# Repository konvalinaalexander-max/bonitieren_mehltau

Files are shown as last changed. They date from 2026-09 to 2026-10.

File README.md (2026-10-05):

# Bonitieren Mehltau

Handy-App zur Bonitur von Falschem Mehltau an Basilikum: Topf in eine Fotobox
mit einheitlichem Licht stellen, von oben fotografieren – die App misst
Pflanzenfläche und Anteil gesund-grüner, gelblicher und brauner Blattfläche
und leitet daraus eine Befallsnote ab (sichtbare Symptome von oben, keine
Mehltau-Diagnose).

**Stand (05.10.2026):** Analyse-Kern, Analyse-Werkstatt, Handy-App, Druckseite
für Topf-Karten und die Pilot-Vorlagen sind vorab gebaut und mit künstlichen
Fotos getestet. Als Nächstes: Entscheidungen aus Etappe 0, Fotobox bauen,
Pilot. Details in [docs/FORTSCHRITT.md](docs/FORTSCHRITT.md).

## Programme

| Was | Wo | Wofür |
|---|---|---|
| Handy-App | [`app/`](app/) | am Box-Handy: Sitzungen, Fotos, Analyse, Export |
| Analyse-Werkstatt | [`werkstatt/`](werkstatt/), als Einzeldatei [`dist/analyse-werkstatt.html`](dist/analyse-werkstatt.html) | am PC: Pilot auswerten, Einrichten, Schwellen, Go/No-Go |
| Druckseite | [`etiketten/`](etiketten/) | Topf-Karten mit QR-Code, Maßstab-Karte |
| Vorlagen | [`vorlagen/`](vorlagen/) | Topf-Karten P001–P200, Pilot-Excel, Bonitur-Bogen |

Nach dem Einschalten von GitHub Pages (Quelle „GitHub Actions“) erscheinen App,
Werkstatt und Druckseite unter `https://<konto>.github.io/bonitieren_mehltau/`.

## Unterlagen

- [docs/So_geht_es_weiter.pdf](docs/So_geht_es_weiter.pdf) – **einfach erklärt:** was das Programm ist, wie die fertige App für Versuche aussieht und die nächsten Schritte
- [docs/Leitfaden_Mehltau-Bonitur.pdf](docs/Leitfaden_Mehltau-Bonitur.pdf) – **Leitfaden:** Schritt für Schritt von der Fotobox bis zur fertigen App
- [docs/SPEZIFIKATION.md](docs/SPEZIFIKATION.md) – verbindliche Zahlen, Entscheidungen und technische Vorgaben
- [docs/FORTSCHRITT.md](docs/FORTSCHRITT.md) – Stand der Bausteine B1–B9
- [CLAUDE.md](CLAUDE.md) – Projektregeln und Aufbau für die Arbeit mit Claude
- [KONZEPT.md](KONZEPT.md) – Machbarkeit, Messprinzip, Fotobox, App, Fahrplan
- [RECHERCHE.md](RECHERCHE.md) – Selbst bauen oder fertige App? Marktüberblick mit Quellen

## Für Entwickler

```
npm ci        # einmalig (esbuild für die Einzeldatei der Werkstatt, Playwright für den Browser-Test)
npm test      # alle automatischen Tests
npm run test:browser       # Ablauf von App, Werkstatt und Druckseite im Browser (Playwright)
node werkzeuge/bauen.mjs   # dist/analyse-werkstatt.html neu bauen
```

App und Werkstatt laufen ohne Build direkt aus den Ordnern, z. B. mit
`python3 -m http.server` im Hauptordner und `http://localhost:8000/app/`.

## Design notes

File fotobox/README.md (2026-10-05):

# Druckteile für die Fotobox

Hier liegen alle 3D-Druckteile für die Fotobox aus Kapitel 4 des Leitfadens.

| Datei / Ordner | Was ist das? |
|---|---|
| `fotobox_teile.scad` | **Die eine Zeichnungsdatei** mit allen 8 Teilen. Wird mit OpenSCAD geöffnet. Alle Maße stehen oben als Zahlen und lassen sich im „Customizer“ ändern. |
| `stl/` | Fertige Druckdateien (STL) mit den **Standardwerten**. Die Datei gibst du deinem Slicer (z. B. PrusaSlicer, Cura, Bambu Studio). |
| `vorschau/` | Bilder der Teile, so wie sie auf dem Druckbett liegen. |

> **Wichtig:** Einige Standardwerte sind nur **Platzhalter** (z. B. Handy-Maße und
> Topf-Maße). Diese Teile erst drucken, wenn du deine eigenen Maße eingetragen hast –
> siehe „Was du messen musst“ und die Platzhalter-Liste am Ende.
>
> Sofort druckbar (wenn deine Teile den Standardmaßen entsprechen): Eckverbinder
> (Leiste genau 20 mm), LED-Leiste (Streifen 10 mm breit), Etikettenhalter
> (Karte 85 × 55 mm), Maßstab-Halter (Karte 100 × 100 mm).
> Erst nach dem Messen: Handyhalter, Zentrierring, Abdeckscheibe, Farbkarten-Halter
> (Dicke der Karte nachmessen).

---

## Die Teile im Überblick

| | Teil (`teil = …`) | Wozu? | Stück | Material |
|---|---|---|---|---|
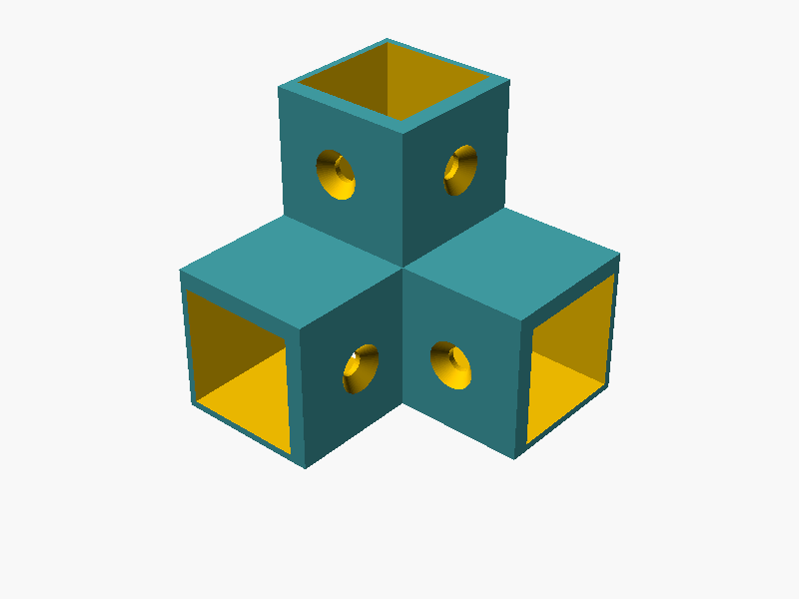
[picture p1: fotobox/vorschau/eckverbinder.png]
|  | **Eckverbinder** (`eckverbinder`) | Verbinden die Leisten zum Rahmen. Jede Ecke hat drei Hülsen: eine senkrechte, zwei waagerechte. Alle 8 Ecken sind gleich; oben wird der Verbinder einfach umgedreht. | **8** | PETG oder PLA, matt schwarz (die 4 unteren sind im Foto) |
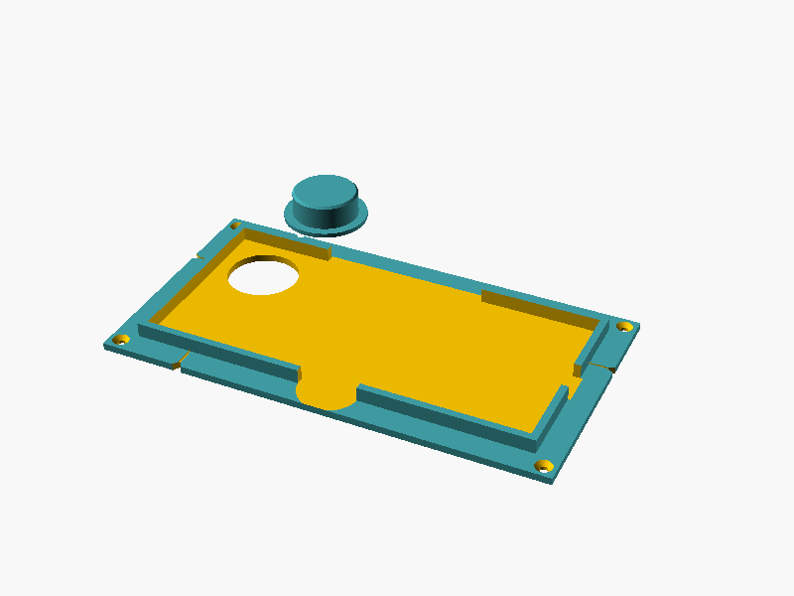
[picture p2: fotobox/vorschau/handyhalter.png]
|  | **Handyhalter** (`handyhalter`) | Liegt auf dem Deckel und hält das Handy flach (Display oben, quer). Die Hauptkamera liegt genau über dem Loch. Mit Aussparungen für Ladekabel und Tasten, Griffmulde, Kerben zum Ausrichten und einem kleinen **Zentrierdorn** (das runde Teil daneben). | **1** (+ 1 Dorn) | PETG oder PLA |
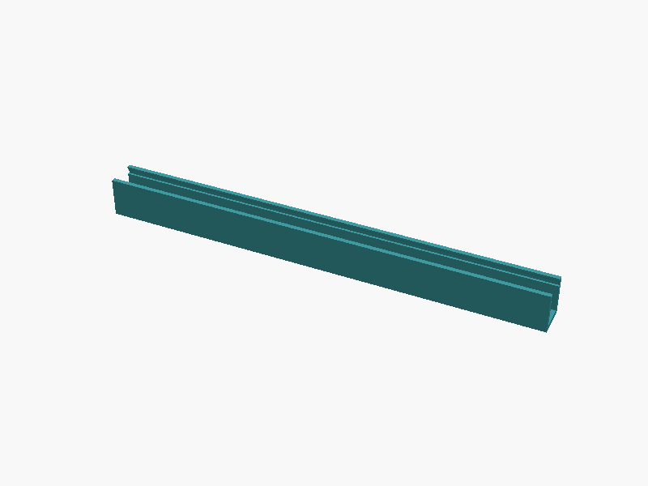
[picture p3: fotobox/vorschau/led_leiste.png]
|  | **LED-Leiste** (`led_leiste`) | Kanal für den LED-Streifen. Vorne hält eine Nut den Diffusor (Milchglasfolie oder Opal-Platte), damit die LEDs nicht direkt auf die Pflanze leuchten. 200 mm lang, 2 Stück je Boxseite. | **8** | PETG (LEDs werden warm) |
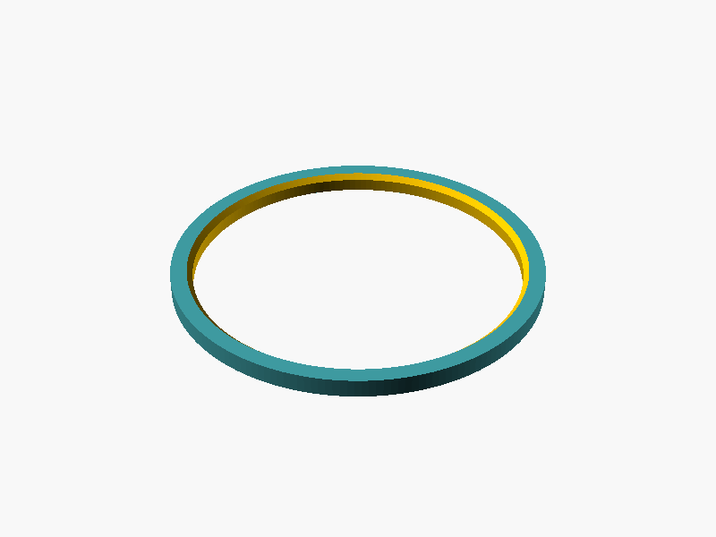
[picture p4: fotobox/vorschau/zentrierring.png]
|  | **Zentrierring** (`zentrierring`) | Flacher Ring auf dem Boden. Der Topf wird hineingestellt und steht so immer an derselben Stelle. | **1 je Topfgröße** | PLA matt schwarz |
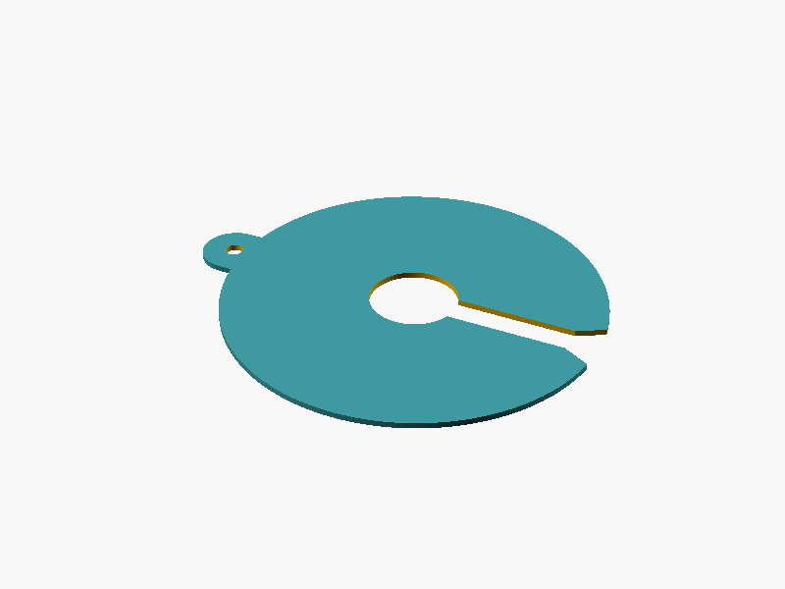
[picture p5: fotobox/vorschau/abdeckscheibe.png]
|  | **Abdeckscheibe** (`abdeckscheibe`) | Dünne Scheibe mit Schlitz und Mittelloch. Deckt Erde und Topfrand ab, damit sie im Foto nicht als „braun“ zählen. Griffnase mit Loch zum Aufhängen. | **2–3 je Topfgröße** | PLA matt schwarz |
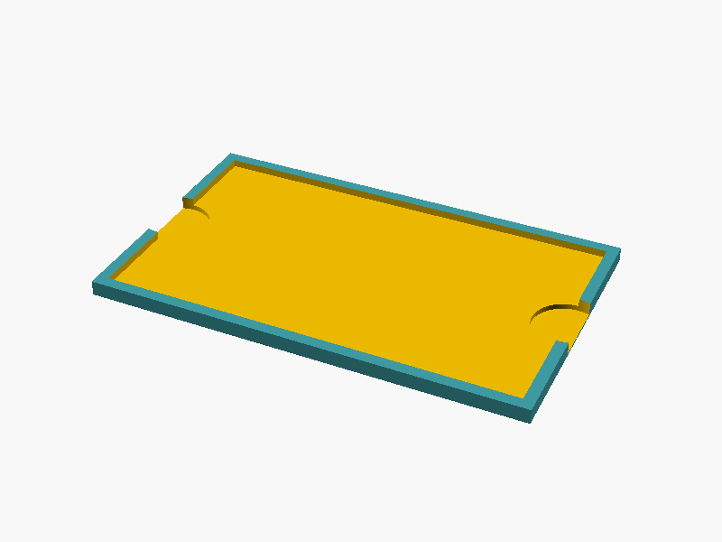
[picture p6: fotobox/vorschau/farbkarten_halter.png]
|  | **Farbkarten-Halter** (`farbkarten_halter`) | Flache Mulde für die Farbkarte (Calibrite ColorChecker Classic Mini). Der Rand ist schmal und liegt **neben** der Karte – er verdeckt keine Farbfelder. | **1** | PLA matt schwarz |
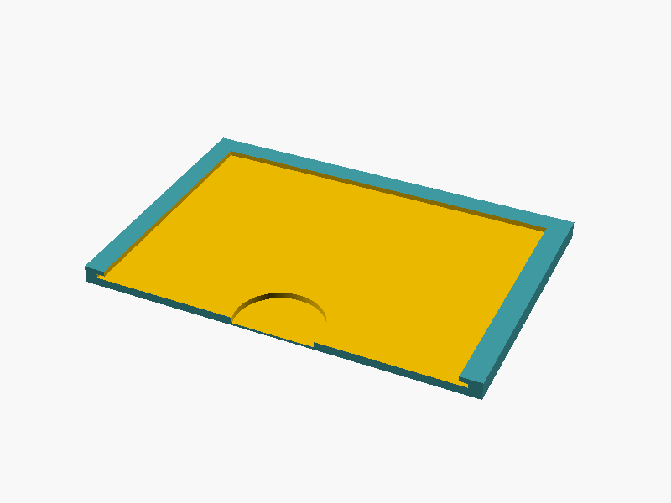
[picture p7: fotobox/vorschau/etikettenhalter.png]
|  | **Etikettenhalter** (`etikettenhalter`) | Flache Tasche für die Topf-Karte (85 × 55 mm). Schmale Lippen an drei Seiten halten das Papier flach, die vierte Seite ist offen zum Einschieben (zur Klappe hin). | **1** | PLA matt schwarz |
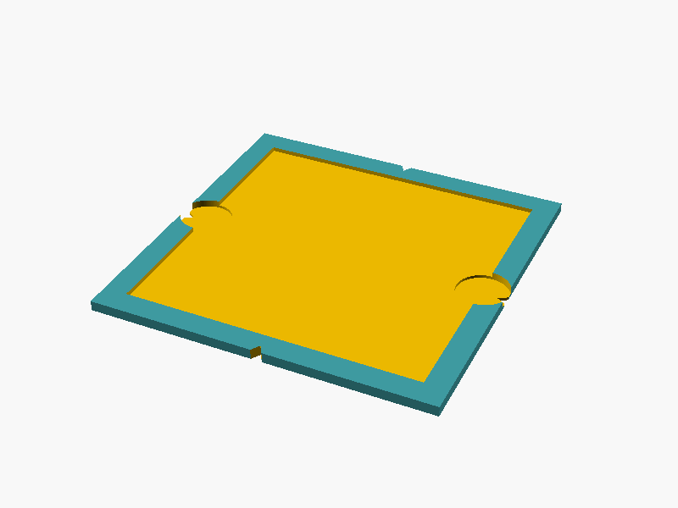
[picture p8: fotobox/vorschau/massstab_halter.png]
|  | **Maßstab-Halter** (`massstab_halter`) | Flache Platte mit Mulde für die Maßstab-Karte 10 × 10 cm. Wird auf Bücher oder eine Kiste in typischer Blatthöhe gelegt und einmal fotografiert. Kerben zeigen die Mitte jeder Seite. | **1** | PLA matt schwarz |

**Alles, was im Foto zu sehen ist, druckst du in mattem Schwarz** (kein glänzendes
„Silk“-Filament): Das Programm sortiert sehr dunkle Bildpunkte aus, und matte Flächen
spiegeln nicht. Eine Rolle Filament reicht für alle Teile.

---

## Druckeinstellungen (Richtwerte)

Allgemein: Düse 0,4 mm, **Schichthöhe 0,2 mm**, **keine Stützen** (alle Teile liegen
in der Datei schon richtig herum: flache Seite unten), 4 Schichten oben und unten.
Die Seite, die später die Kamera sieht, liegt beim Druck oben – auf glatten
Druckplatten wird die Unterseite oft glänzend.

| Teil | Wände (Perimeter) | Füllung (Infill) | Hinweise |
|---|---|---|---|
| Eckverbinder | 4 | 30–40 % | Über den waagerechten Hülsen druckt der Drucker eine Brücke von ca. 21 mm – das geht ohne Stützen. Hängt sie durch: Lüfter auf 100 %, langsamer drucken. **Erst einen Verbinder als Passprobe drucken** und eine Leiste einstecken. |
| Handyhalter | 3 | 20 % | Zuerst prüfen, ob das Handy hineinpasst und die Linse mittig über dem Loch liegt. |
| LED-Leiste | 3 | 20 % | PETG. Bei Verzug Rand (Brim) einschalten. |
| Zentrierring | 3 | 20 % | – |
| Abdeckscheibe | 3 | 100 % | Dünnes Teil, langsam drucken (erste Schicht sauber). |
| Farbkarten-Halter, Etikettenhalter, Maßstab-Halter | 3 | 15–20 % | Mit hohem Sockel (`sockel_hoehe`) reichen 10–15 % Füllung. |

Bei PLA ca. 200–215 °C Düse und 60 °C Bett, bei PETG ca. 230–245 °C und 70–80 °C
(Herstellerangaben auf der Rolle haben Vorrang).

---

## So trägst du deine Maße ein (OpenSCAD)

1. **OpenSCAD installieren:** kostenlos von [openscad.org](https://openscad.org/)
   (Windows, macOS, Linux).
2. **Datei öffnen:** „File“ → „Open“ → `fotobox_teile.scad`.
3. **Customizer einblenden:** Rechts erscheint die Leiste „Customizer“. Falls nicht:
   Menü „Window“ (deutsch „Fenster“) → Haken bei „Hide Customizer“ entfernen.
4. **Teil wählen:** Ganz oben bei `teil` das gewünschte Teil aus der Liste wählen.
5. **Maße eintragen:** Die Gruppen (z. B. „Handyhalter“) aufklappen und die Zahlen
   ändern. Alle Maße in **Millimetern**, Kommazahlen mit **Punkt** schreiben
   (`63.5`, nicht `63,5`). Ein Haken bedeutet „ja“, kein Haken „nein“.
6. **Vorschau:** F5 (schnell). **Rendern:** F6 – dauert Sekunden bis zu einer Minute,
   erst danach lässt sich exportieren.
7. **Exportieren:** F7 bzw. „File“ → „Export“ → „Export as STL…“, Dateiname z. B.
   `handyhalter.stl`. Für jedes Teil wiederholen: Teil wählen, F6, F7.
8. **Meldungen lesen:** Unten im Fenster „Console“ (sonst „Window“ → „Console“)
   stehen Zeilen mit `ECHO`:
   - `OK: …` – das Teil passt aufs Druckbett.
   - `WARNUNG: …` – etwas passt nicht (z. B. zu groß fürs Druckbett). Erst beheben.
   - `HINWEIS: …` – nützliche Werte, z. B. Breite des Diffusorstreifens.
   - `ZUSCHNITT: …` – beim Eckverbinder: die Längen der Leisten für deine Maße.
9. **Werte sichern:** Damit deine Maße nicht verloren gehen, oben im Customizer mit
   dem „+“-Knopf einen Parametersatz anlegen (z. B. „Meine Box“) und speichern.
   OpenSCAD legt dann neben der `.scad`-Datei die Datei `fotobox_teile.json` an.
   Alternativ die Zahlen direkt links im Text ändern und mit Strg+S speichern.

**Passungs-Spiel:** Klemmt die Leiste im Eckverbinder, `spiel` um 0.1 erhöhen; wackelt
sie, um 0.1 verringern. Für Handy und Karten gibt es eigene Werte (`handy_spiel`,
`karten_spiel`).

---

## Was du messen musst

Messen mit dem Messschieber, in Millimetern. Bei den Töpfen jeweils 3 Töpfe messen
und den **größten** Wert nehmen. Hast du mehrere Topfgrößen, druckst du für jede
Größe einen eigenen Zentrierring und eigene Abdeckscheiben.

### Topf und Pflanze (Maße A–G aus Tabelle 3.2 des Leitfadens)

| Maß | Bedeutung | Einstellung in der Datei | Für welches Teil |
|---|---|---|---|
| **A** | Topf oben, Außenkante Rand | `topf_oben_A` | Abdeckscheibe (Durchmesser = A + 10 mm) |
| **B** | Topf unten (Boden außen) | `topf_unten_B` | Zentrierring (innen = B + 1 mm) |
| **G** | Stängel-Büschel über der Erde | `stiel_loch_G` | Mittelloch der Abdeckscheibe (ca. 30 mm) |
| C, D, E, F | Topfhöhe, Pflanzenbreite und -höhe | – (nur für die Box-Höhe) | Ergibt im Karton-Test die Innenhöhe → `box_hoehe` |

### Handy (immer **ohne Hülle** messen – es liegt immer ohne Hülle im Halter)

| Was | Einstellung |
|---|---|
| Länge (lange Seite), Breite (kurze Seite), Dicke | `handy_laenge`, `handy_breite`, `handy_dicke` |
| Mitte der **Hauptkamera-Linse**: Handy hochkant **von hinten** ansehen (Kamera oben). Abstand der Linsenmitte zur **oberen** Kante und zur **linken** Kante. | `linse_von_oben`, `linse_von_links` |
| Kamera-Insel (Buckel), falls sie vorsteht und größer als das 30-mm-Loch ist: von hinten gesehen Abstand ihrer oberen linken Ecke zur oberen und linken Kante, dazu Breite und Höhe. Sonst alles auf 0 lassen. | `insel_von_oben`, `insel_von_links`, `insel_breite`, `insel_hoehe` |
| Seitentasten: Handy **von vorne** (Display) hochkant ansehen – sind die Tasten rechts oder links? Von wo bis wo (Abstand ab der oberen Kante)? | `tasten_seite`, `tasten_von`, `tasten_bis` |
| Ladebuchse: meist unten in der Mitte (dann 0). | `kabel_versatz` |

```
  1) Messen: Handy von HINTEN,        2) Im Halter, von oben gesehen (Display oben),
     hochkant, Kamera oben               Einstellung handy_oben = "links":

      obere Kante                                    hinten
     ┌───────────┐                       ┌──────────────────────────────┐
     │   ◉       │ ◉ = Hauptkamera  obere│ ◉                            │untere Kante
     │           │                  Kante│                              │mit Ladebuchse
     │           │                       └──────────────────────────────┘
     │           │                                vorne (Griffmulde)
     │           │
     └───────────┘                    Die lange Handyseite liegt links–rechts (Querformat).

  linse_von_oben  = Abstand von ◉ (Mitte) bis zur oberen Kante
  linse_von_links = Abstand von ◉ (Mitte) bis zur linken Kante (von hinten gesehen!)
```

**Welche Linse ist die Hauptkamera?** Kamera-App auf „1×“ stellen und nacheinander
jede Linse mit dem Finger abdecken. Wird das Vorschaubild dunkel, ist es die
Hauptkamera.

`handy_oben` legt fest, ob die Oberkante des Handys im Halter links oder rechts liegt
(von oben aufs Display gesehen). Beides geht; wähle die Seite, bei der die Tasten gut
erreichbar sind (mit der Lautstärketaste wird ausgelöst). Im Querformat zeigt die
lange Handyseite immer nach links und rechts.

### Rahmen, Platten und Zubehör

| Was | Einstellung |
|---|---|
| Holzleiste nachmessen (oft nicht genau 20 mm!) – oder Alu-Profil 2020 = 20 | `leiste` |
| Dicke der Wand- und Deckelplatten | `platten_dicke` |
| Durchmesser des Lochs im Deckel (Lochsäge) | `deckel_loch_d` |
| Breite des LED-Streifens | `led_breite` |
| Dicke der Diffusorfolie bzw. Opal-Platte | `diffusor_dicke` |
| Farbkarte außen (Breite × Länge) und Dicke | `farbkarte_breite`, `farbkarte_laenge`, `farbkarte_dicke` |
| Topf-Karte (Vorschlag 85 × 55 mm) und Dicke | `etikett_laenge`, `etikett_breite`, `etikett_dicke` |
| Maßstab-Karte (100 × 100 mm, Papier auf Karton) und Dicke | `massstab_karte`, `massstab_dicke` |
| Größe deines Druckbetts | `druckbett_x`, `druckbett_y`, `druckbett_z` |
| Innenhöhe laut Karton-Test (Standard 700 mm) | `box_hoehe` |

---

## Zuschnittliste (Innenmaß 500 × 500 mm, Höhe 700 mm)

So ist der Rahmen gebaut: Die **senkrechten Leisten** stecken ganz durch die
Eckverbinder und stehen unten auf der Bodenplatte bzw. reichen oben bis an den Deckel.
Die **waagerechten Leisten** stecken in den seitlichen Hülsen und stoßen innen an die
senkrechte Leiste. Über die Eckverbinder gemessen ist der Rahmen dann
500 × 500 × 700 mm; die Platten kommen außen darauf.

### Leisten (Holz 20 × 20 mm oder Alu-Profil 2020)

| Leiste | Stück | Länge |
|---|---|---|
| senkrecht (Ecken) | 4 | **700 mm** (= Innenhöhe `box_hoehe`) |
| waagerecht (4 unten, 4 oben) | 8 | **457 mm** (lieber 0,5 mm kürzer als länger) |

Rechenweg: waagerecht = Innenmaß − 2 × (Außenwand + Spiel + Leistenmaß)
= 500 − 2 × (1,2 + 0,3 + 20) = **457 mm**.
Änderst du `leiste`, `eck_wand_aussen`, `spiel`, `box_innen` oder `box_hoehe`, zeigt
OpenSCAD die neuen Längen beim Eckverbinder in der Zeile `ZUSCHNITT` an.
Gleich lange Diagonalen je Seite = Rahmen ist rechtwinklig.

### Platten

| Platte | Stück | Maß | Material | Hinweis |
|---|---|---|---|---|
| Rückwand, 2 Seitenwände | 3 | 500 × 700 mm | Forex 3–5 mm matt weiß oder Kapa 5 mm | matte Seite nach innen |
| Vorderwand = Klappe | 1 | 500 × 700 mm | wie oben | 2 Scharniere + 2 Magnete (oder nur Magnete) |
| Boden | 1 | 500 × 500 mm | Forex, Sperrholz o. ä. | Oberseite matt schwarz oder dunkelgrau, z. B. mit schwarzem Moosgummi bekleben; der Rahmen steht darauf |
| Deckel | 1 | 500 × 500 mm | Forex matt weiß | **Loch Ø 30 mm genau in der Mitte** (Schnittpunkt der Diagonalen) |

**Lichtdicht machen:** Die Eckverbinder sind außen 1,2 mm dick. Darum liegen die Platten
an den Ecken auf den Verbindern und haben zu den Leisten ca. 1,5 mm Abstand. Am
einfachsten klebst du die Platten mit **Montageband (doppelseitiges Schaumklebeband,
ca. 1,5 mm dick)** auf die Leisten – dann liegen sie überall plan. Um die Öffnung der
Klappe ein schwarzes Schaumstoff-Dichtband (2–3 mm) kleben, damit sie ohne Lichtspalt
schließt.

### Schrauben (optional)

| Wofür | Was | Stück |
|---|---|---|
| Eckverbinder – Holzleisten | Senkkopf-Holzschrauben 3,5 × 16 mm | bis 32 (4 je Verbinder) |
| Eckverbinder – Alu-Profil 2020 | M5 × 10 mm Linsenkopf + Hammermutter Nut 6; dazu `eck_schraube_d = 5.5` und `eck_senkung` aus | bis 32 |
| LED-Leisten | Senkkopf-Holzschrauben 3 × 12 mm (oder Montageband) | 16 |
| Handyhalter auf dem Deckel | M3 × 12 mm Senkkopf + Mutter (oder Montageband) | 4 |
| Farbkarten- und Etikettenhalter | Standard: kleben. Schrauben nur bei dickem Boden (`befestigung = "schrauben"`) | 2 je Halter |

---

## Wo kommt welches Teil hin? (Ergänzung zu Abschnitt 4.6 im Leitfaden)

1. **Rahmen:** 4 Eckverbinder unten (senkrechte Hülse zeigt nach oben), 4 oben
   (umgedreht). Die Schraublöcher zeigen immer nach innen in die Box.
2. **LED-Leisten:** je Seite 2 Stück innen an die obere waagerechte Leiste, zwischen die
   Eckverbinder (je Seite sind ca. 406 mm Platz). Der LED-Streifen klebt im Kanal und
   läuft an den Ecken einfach um die Kurve weiter. Den Diffusorstreifen
   (**12,2 mm breit** zuschneiden) von der Stirnseite in die Nuten schieben.
3. **Handyhalter:** Deckel festschrauben. Halter auflegen, den **Zentrierdorn** (Kragen
   oben) durch das Loch im Halter in das Deckel-Loch stecken – jetzt liegen beide Löcher
   genau übereinander. Die 4 Kerben am Rand zeigen die Linsenmitte: Zeichne durch die
   Deckelmitte ein Kreuz parallel zu den Kanten und lege die Kerben darauf. Halter
   festschrauben oder kleben, Dorn herausnehmen, Handy ohne Hülle einlegen,
   Wasserwaage aufs Display.
4. **Farbkarten-Halter:** hinten links in die Ecke, **mindestens 25 mm von beiden
   Wänden** (dort sitzen Leiste und Eckverbinder). Karte immer gleich herum einlegen.
5. **Etikettenhalter:** vorne rechts, ebenfalls mindestens 25 mm von den Wänden. Die
   **offene Seite zeigt zur Klappe**; die Topf-Karte wird mit der Nummer nach oben
   eingeschoben.
6. **Zentrierring:** Topf hineinstellen, Ring lose in die Mitte, Testfoto, verschieben
   bis der Topf genau in der Bildmitte steht – erst dann festkleben.
7. **Abdeckscheiben:** mit dem Loch in der Griffnase an einen Haken an der Box hängen.
8. **Maßstab-Halter:** nur für das Maßstab-Foto (Leitfaden 8.2): Karte einlegen, Halter
   auf eine Unterlage in typischer Blatthöhe legen (Kiste oder umgedrehter Topf auf
   Büchern), mittig unter die Kamera (Kerben helfen), fotografieren.

---

## Wenn etwas nicht passt

| Problem | Lösung |
|---|---|
| Leiste klemmt im Eckverbinder | `spiel` um 0.1 erhöhen (oder Leiste nachmessen → `leiste`) |
| Leiste wackelt | `spiel` um 0.1 verringern; sonst festschrauben |
| Brücke im Eckverbinder hängt durch | Lüfter 100 %, langsamer; die Brücke ist innen und stört nicht |
| `WARNUNG: … passt NICHT auf das Druckbett` | Druckbett-Maße prüfen; bei der Abdeckscheibe ggf. `griffnase` aus; bei der LED-Leiste `led_laenge` kürzer |
| `WARNUNG: Das Linsenloch … ragt über das Handy hinaus` | Linsenposition prüfen; `halter_linsenloch_d` kleiner (Wert steht in der Meldung) |
| Handy liegt schief | Kamera-Buckel stößt an: `insel_…`-Werte eintragen |
| Handy klemmt oder wackelt | `handy_spiel` ändern (je Seite) |
| Karte klemmt im Halter | `karten_spiel` erhöhen |
| Topf-Karte wölbt sich | `etikett_lippe` etwas größer oder dickere Karte |
| Blätter verdecken Farbkarte oder Etikett | `sockel_hoehe` erhöhen (z. B. 100) und Halter neu drucken |
| Topf steht nicht ganz unten im Ring | `ring_zugabe` erhöhen oder `ring_hoehe` verringern |

---

## Platzhalter – diese Werte musst du selbst messen

Diese Standardwerte sind nur Beispiele. Vor dem Drucken der betroffenen Teile ersetzen:

| Einstellung | Standard | Betrifft |
|---|---|---|
| `handy_laenge`, `handy_breite`, `handy_dicke` | 160, 75, 9 | Handyhalter |
| `linse_von_oben`, `linse_von_links` | 20, 20 | Handyhalter |
| `insel_von_oben`, `insel_von_links`, `insel_breite`, `insel_hoehe` | 0 (keine) | Handyhalter, nur bei Kamera-Buckel |
| `tasten_seite`, `tasten_von`, `tasten_bis`, `kabel_versatz` | rechts, 40, 110, 0 | Handyhalter |
| `topf_unten_B` (Maß B) | 90 | Zentrierring |
| `topf_oben_A` (Maß A) | 120 | Abdeckscheibe |
| `stiel_loch_G` (Maß G) | 30 | Abdeckscheibe |
| `farbkarte_dicke` (Breite/Länge 63.5 × 109 ebenfalls nachmessen) | 2 | Farbkarten-Halter |
| `leiste` (Holzleiste nachmessen) | 20 | Eckverbinder, Zuschnitt |
| `platten_dicke`, `deckel_loch_d` | 5, 30 | Zentrierdorn |
| `led_breite`, `diffusor_dicke` | 10, 1 | LED-Leiste |
| `etikett_dicke`, `massstab_dicke` | 0.5, 1.5 | Etiketten- und Maßstab-Halter |
| `box_hoehe` (aus dem Karton-Test) | 700 | Zuschnitt senkrechte Leisten |
| `druckbett_x`, `druckbett_y`, `druckbett_z` | 220, 220, 250 | Warnungen |

---

## Technische Hinweise

- Geprüft mit OpenSCAD 2021.01: Alle 8 Teile rendern mit den Standardwerten fehlerfrei
  (je ein geschlossener Körper; der Handyhalter hat zusätzlich den getrennten
  Zentrierdorn).
- Export ohne Oberfläche, z. B.:
  `openscad -o stl/eckverbinder.stl -D 'teil="eckverbinder"' fotobox_teile.scad`
- Mit gespeichertem Parametersatz:
  `openscad -p fotobox_teile.json -P "Meine Box" -o stl/handyhalter.stl -D 'teil="handyhalter"' fotobox_teile.scad`
- Vorschaubild: `openscad --render -o vorschau/handyhalter.png --imgsize=800,600 --viewall --autocenter -D 'teil="handyhalter"' fotobox_teile.scad`
- Alle Parameter stehen oben in der einen Datei (keine `include`/`use`), damit der
  Customizer sie anzeigt. Abgeleitete Werte stehen unter `/* [Hidden] */`.

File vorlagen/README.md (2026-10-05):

# Vorlagen

Druck- und Excel-Vorlagen für Pilot und Betrieb. Sie enthalten keine Betriebsdaten.

| Datei | Wofür | Hinweise |
|---|---|---|
| `topfkarten_pilot.pdf` | Topf-Karten P001–P200 (85 × 55 mm, 10 je A4-Seite, 20 Seiten) | große Nummer und QR-Code mit der Topf-ID; die Werkstatt ordnet Fotos damit auch ohne Dateinamen zu |
| `massstab_karte.pdf` | Maßstab-Karte 10 × 10 cm (2 je Seite, eine als Ersatz) | gemessen wird die äußere Kante des schwarzen Rahmens |
| `pilot_bonitur_vorlage.xlsx` | Excel für den Pilot: Blätter „Bonitur“, „Wiederholung“, „Lichttest“, „Anleitung“ | Spalten wie in `docs/SPEZIFIKATION.md`; Auswahllisten für Noten (0–4), ja/nein, Zeitpunkt, Hallenlicht |
| `bonitur_bogen_pilot.pdf` | Kopiervorlage Bonitur-Bogen (Leitfaden 6.8) | je Person und Sitzung ein Bogen |
| `projekttagebuch.xlsx` | Projekttagebuch (Leitfaden 1.6) | nach jedem Arbeitsschritt eine Zeile: Datum, Erledigtes, Entscheidungen, offene Fragen |

## Drucken

- Im Druckdialog **„Tatsächliche Größe“ bzw. „100 %“** wählen, nicht „An Seite anpassen“.
- Danach das Kontrollmaß oben auf der Seite nachmessen: genau 50 mm. Eine Karte nachmessen: 85 × 55 mm.
- Mattes Papier oder dünnen Karton verwenden, nicht glänzend laminieren (Spiegelungen).

## Andere Nummern drucken

Die Druckseite [`etiketten/`](../etiketten/) erzeugt Karten für beliebige Nummern (Bereich, Liste
oder aus Excel), wahlweise mit oder ohne QR-Code, mit Satz und Sorte in kleiner Schrift.
Im Browser öffnen → Nummern eintragen → „Drucken …“ (oder „Als PDF speichern“).

## Neu erzeugen

- Excel und Bonitur-Bogen: `python3 werkzeuge/vorlagen-erzeugen.py` (braucht `openpyxl` und `pypdf`).
- Topf-Karten und Maßstab-Karte: Druckseite `etiketten/?praefix=P&von=1&bis=200&stellen=3` bzw.
  `etiketten/?art=massstab` im Browser öffnen und als PDF drucken.

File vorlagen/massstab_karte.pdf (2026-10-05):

Kontrollmaß: genau 50 mm? Sonst mit „Tatsächliche Größe/100 %“ neu drucken. · Seite 1 von 1

# Maßstab-Karte

10 × 10 cm

Die äußere Kante des schwarzen Rahmens misst genau 100 × 100 mm – bitte nachmessen. Entlang der gestrichelten Linie ausschneiden, auf festen Karton kleben, matt lassen. In der Box auf einen Sockel in typischer Blatthöhe legen und einmal fotografieren. In der Werkstatt die 4 äußeren Ecken des schwarzen Rahmens anklicken.

Mehltau-Bonitur · Maßstab-Karte

# Maßstab-Karte

10 × 10 cm

Die äußere Kante des schwarzen Rahmens misst genau 100 × 100 mm – bitte nachmessen. Entlang der gestrichelten Linie ausschneiden, auf festen Karton kleben, matt lassen. In der Box auf einen Sockel in typischer Blatthöhe legen und einmal fotografieren. In der Werkstatt die 4 äußeren Ecken des schwarzen Rahmens anklicken.

Mehltau-Bonitur · Maßstab-Karte

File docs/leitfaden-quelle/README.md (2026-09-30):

# Quelldateien des Leitfadens

Aus diesen Dateien entsteht `docs/Leitfaden_Mehltau-Bonitur.pdf`.

- `chapters/*.html`: Kapitel als HTML-Fragmente (Reihenfolge in `build.py`)
- `style.css`, `fonts/`, `title_art.svg`: Gestaltung und Titelbild
- `STYLE.md`: erlaubte HTML-Bausteine und Schreibregeln für Kapitel
- `build.py`: setzt alles zusammen und erzeugt das PDF in zwei Durchläufen
  (der zweite trägt die Seitenzahlen ins Inhaltsverzeichnis ein)
- `preview.py`: zeigt ein einzelnes Kapitel als PNG-Seiten zur Kontrolle

## PDF neu erzeugen

Voraussetzungen: Node.js mit `playwright` (Chromium), Python 3 mit `pypdf`,
`pypdfium2` und `pillow`.

```bash
cd docs/leitfaden-quelle
NODE_PATH=$(npm root -g) python3 build.py
```

Das PDF landet in `docs/Leitfaden_Mehltau-Bonitur.pdf`. Wenn sich Zahlen oder
Entscheidungen ändern, zuerst `docs/SPEZIFIKATION.md` anpassen, dann die
betroffenen Kapitel, dann neu erzeugen.

Schriften: Source Sans 3, Source Serif 4 und Source Code Pro (SIL Open Font
License 1.1).

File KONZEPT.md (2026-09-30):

# Konzept: Mehltau-Bonitur von Basilikum per Handy

Stand: Ideen- und Planungsphase. Noch kein Code.

> Die ausgearbeitete Schritt-für-Schritt-Anleitung steht im Leitfaden
> [docs/Leitfaden_Mehltau-Bonitur.pdf](docs/Leitfaden_Mehltau-Bonitur.pdf),
> die verbindlichen Zahlen in [docs/SPEZIFIKATION.md](docs/SPEZIFIKATION.md).
> Bei Abweichungen gelten diese beiden Dateien.

## 1. Kurzfazit

**Machbar – ja.** Das Grundprinzip (Foto unter kontrolliertem Licht → Pixel nach
Farbe einteilen → Anteil gelber/brauner Blattfläche berechnen) ist in der
Pflanzenforschung Standard und erprobt, z. B.:

- **PlantCV** – Open-Source-Bildanalyse für Pflanzen-Phänotypisierung (Python),
  inkl. Farbkorrektur mit Farbkarte und Farbanalyse von Blattflächen.
- **Leaf Doctor** – Smartphone-App, die Krankheitsbefall über Farbschwellen
  schätzt.
- **APS Assess** – klassische Software zur Befallsschätzung über Farbanteile.

**Schwierigkeit:** Die Programmierung ist mittelschwer, aber gut machbar. Der
eigentlich schwierige Teil ist nicht der Code, sondern:

1. **gleichbleibende Fotos** (→ genau dafür ist die Box da – sehr gute Idee),
2. **Kalibrierung**: die App so einstellen, dass ihre Note mit der Note eurer
   erfahrenen Leute übereinstimmt. Dafür braucht es echte, von Menschen
   bonitierte Fotos.

| Baustein | Schwierigkeit | Kommentar |
|---|---|---|
| Fotobox bauen | leicht–mittel | Maker-Projekt, 3D-Druck + Platten + LED |
| Grün-/Gelb-/Braunanteil messen | mittel | Standard-Bildverarbeitung |
| Pflanzengröße (Fläche) messen | leicht–mittel | Pixel zählen + Maßstab |
| Handy-App mit Kamera, Speichern, Export | mittel | Standard-Web-App |
| Note, die mit Experten übereinstimmt | mittel–schwer | steht und fällt mit Kalibrierdaten |
| KI-Modell (falls Farbschwellen nicht reichen) | schwer | erst später und nur wenn nötig |

**Selbst bauen oder fertige App?** Eine fertige App, die das kann, gibt es nicht
(Recherche Stand 09/2026) → selbst bauen, in Etappen, mit vorhandenen
Gratis-Bausteinen. Details und Quellen: [RECHERCHE.md](RECHERCHE.md).

---

## 2. Was die App messen kann – und was nicht

**Falscher Mehltau an Basilikum** (*Peronospora belbahrii*):

- Oberseite: Aufhellung/Gelbfärbung (Chlorose), oft von Blattadern begrenzt
- Unterseite: grau-violetter bis schwarzer Sporenrasen
- später: braune Nekrosen, Blattfall

Von oben sieht die Kamera die **Blattoberseite**, also Gelbfärbung und
Braunfärbung. Das passt gut zu eurem Ziel.

**Messbar:**

- Pflanzenfläche von oben (Pixel bei fester Kamerahöhe; cm² nur ungefähr,
  weil die Blätter auf unterschiedlicher Höhe liegen) → Maß für Größe/Wachstum
- Anteil gesund-grün / gelblich / braun an der Pflanzenfläche (%)
- mittlerer „Grünwert" der Pflanze (stufenlose Kennzahl für Vergilbung)
- daraus abgeleitet: Befallsnote nach eurer Skala

**Nicht (direkt) messbar:**

- **Frühe Infektion** ohne sichtbare Vergilbung (Sporen nur auf der Unterseite)
- **Untere Blätter**, die von oberen verdeckt sind – laut Beratungsliteratur
  (z. B. University of Minnesota Extension) beginnt der Befall unten und wandert
  nach oben → die App wird frühen/unteren Befall unterschätzen und hinterherhinken.
  Für Vergleiche (Behandlung A vs. B, Verlauf über die Zeit) ist das weniger
  kritisch, solange immer gleich fotografiert wird. **Der Pilot muss prüfen, wie
  groß dieser Effekt ist.**
- **Ursache der Vergilbung**: Gelb kann auch von Nährstoffmangel (N, Fe, Mg),
  Staunässe, Lichtmangel oder alten Blättern kommen. Die App misst
  „Vergilbung", nicht den Pilz. Ein Mensch muss die Ursache kennen/prüfen.
  Das Ergebnis heißt deshalb **„sichtbare Symptome (von oben)"**, nicht
  „Mehltau-Diagnose". Eine regelmäßige Kontrolle der Blattunterseite bleibt nötig.
- **Pflanzenhöhe**: mit einem Foto von oben nicht direkt messbar (nur Fläche).
  Falls Höhe wichtig ist: Maßskala an der Innenwand + zweites Foto von der Seite,
  oder später Tiefensensor (LiDAR bei manchen iPhones).

---

## 3. Wie die Bilderkennung funktioniert (Schritt für Schritt)

```
Foto ──► Farbkorrektur ──► Box-Bereich ausschneiden ──► Pflanze vom Hintergrund trennen
                                                                 │
     Ergebnis + Kontrollbild ◄── Kennzahlen berechnen ◄── Pflanzenpixel einfärben:
                                                           grün / gelb / braun
```

1. **Foto** in der Box: gleicher Abstand, gleiches Licht, Topf immer an
   derselben Stelle.
2. **Farbkorrektur**: Im Bild liegt immer eine **Farbkarte** (24 Farbfelder,
   siehe Kapitel 4). Die App rechnet die Farben so um, dass die Karte immer gleich
   aussieht. Damit gleichen wir aus, dass die Handykamera Belichtung und
   Weißabgleich selbst verstellt.
3. **Ausschneiden**: Da die Box fix ist, ist der relevante Bildbereich immer
   gleich. Optional: kleine Markierungen (ArUco/QR-Marker) in den Bodenecken,
   dann findet die App Bereich und Maßstab automatisch.
4. **Pflanze vs. Hintergrund**: Jeder Pixel hat einen **Farbton** (0–360°),
   eine **Sättigung** und eine **Helligkeit**. Pflanzenpixel sind gelb bis grün
   und ausreichend gesättigt. Erde (dunkel, braun, wenig gesättigt), Topf und
   Boden werden verworfen. Weil Erde und braune Blätter sich farblich ähneln,
   wird die Erde zusätzlich abgedeckt (Abdeckscheibe, siehe Kapitel 4).
5. **Einteilung der Pflanzenpixel**, grob zur Veranschaulichung (die echten
   Grenzwerte werden mit euren Fotos eingestellt):
   - Farbton ca. > 80° → **gesund grün** (typisches Basilikumgrün ≈ 90–110°)
   - Farbton ca. 45–80° → **gelblich / chlorotisch**
   - Farbton ca. < 45° und eher dunkel → **braun / nekrotisch**
   - sehr hell, kaum Farbe → **Glanzlicht**, wird ignoriert
6. **Kennzahlen**: Pixel zählen → Pflanzenfläche (Pixel bzw. ungefähre cm²),
   % gelb, % braun, mittlerer Grünwert → Note.
7. **Kontrollbild**: Die App zeigt das Foto mit eingefärbten Bereichen (grün /
   gelb / rot). So sehen Mitarbeiter sofort, ob die App sinnvoll erkannt hat –
   wichtig für Vertrauen und zum Aufspüren von Fehlern.
8. **Speichern**: Originalfoto + Ergebnis + Zusatzinfos (Datum, Satz, Sorte,
   Tisch, Behandlung, Mitarbeiter).

> **Wichtig: Originalfotos immer aufheben.** Dann kann man später mit einer
> verbesserten Auswertung (oder einem KI-Modell) alle alten Fotos neu
> auswerten, ohne neu fotografieren zu müssen.

---

## 4. Die Fotobox

### Größe – eher Quader als Würfel

Die Box muss so hoch sein, dass die Kamera die ganze Pflanze sieht. Faustregel
für die normale Hauptkamera (1×, **nicht** Weitwinkel wegen Verzerrung):

> Abstand Kamera → Pflanzenoberkante ≈ gewünschte Bildbreite (kurze Bildseite)

Beispiel: 12-cm-Topf, Pflanze bis ~25 cm Durchmesser und ~25 cm hoch:

- Box-Innenhöhe 70 cm → Kamera ca. 70 cm über dem Boden, ca. 34 cm über der
  Pflanzenoberkante (Topf ~11 cm + Pflanze ~25 cm) → Bildbreite dort ca. 34 cm
- Grundfläche 50 × 50 cm, damit Farbkarte und Etikett in den Bodenecken
  möglichst nicht von Blättern verdeckt werden

→ Eher ein hoher Quader (50 × 50 × 70 cm, Innenmaß) als ein Würfel.
**Tipp:** Erst mit einem Karton und einer Lampe testen, welche Höhe passt, bevor
gedruckt wird.

### Bauweise

- Die meisten 3D-Drucker haben ~22–25 cm Druckbett → **nur Eckverbinder,
  Handyhalter und LED-Halter drucken**; Kanten aus Alu-Profil (z. B. 2020),
  Holzleisten oder Rundstäben. Stabiler und günstiger als ein komplett
  gedruckter Rahmen.
- **Wände**: matt weiße Platten (Forex/PVC-Hartschaum, Kapa-Platte) → gleichmäßig
  helles, weiches Licht.
- **Boden**: matt und farbneutral (grau oder schwarz) – keine Farbe, die auf die
  Blätter abstrahlt.
- **Topf-Zentrierung**: Ring oder Mulde am Boden, damit der Topf immer mittig
  unter der Kamera steht.
- **Abdeckscheibe für Erde und Topfrand**: eine matte, dunkle (schwarze oder
  dunkelblaue) Scheibe mit Schlitz, die man um die Stängel auf den Topf legt.
  Sonst zählt sichtbare braune Erde als „braunes Blatt". Lässt sich gut drucken.
- **Topf-Etikett im Bild**: Wenn das Etikett mit QR- oder EAN-Code mit im Foto
  ist, liest die App die Topf-ID direkt aus dem Bild. Kein extra Scannen, und
  Foto und ID können nicht vertauscht werden.
- **Deckel**: Oben nicht ganz offen lassen, sondern eine Deckelplatte mit Loch
  für die Kamera (= gleichzeitig Handyhalter). Sonst verändert Raumlicht
  (Sonne, Hallenbeleuchtung) die Fotos.
- **Referenzkarte** fest montiert im Bildfeld, an einer Stelle, die nie von
  Blättern verdeckt wird (im Karton-Test ausprobieren – Bodenecken können bei
  großen Pflanzen verdeckt sein). **Empfehlung: Farbkarte mit 24 Feldern**, z. B.
  Calibrite ColorChecker Classic Mini (Kreditkartengröße, ca. 60–80 €). Eine
  einfache Graukarte korrigiert nur den Weißabgleich, nicht die Farben selbst –
  gerade die Grenze zwischen Grün, Gelb und Braun hängt aber an der Farbtreue.
  PlantCV erkennt diese 24-Feld-Karten automatisch.
  Sauber halten, nicht in der Sonne lagern (verblasst).

### Licht

- **LED-Streifen mit hohem Farbwiedergabeindex (CRI/Ra ≥ 90)**, Tageslichtweiß
  (5000–6500 K). Billige LEDs verfälschen Grün-/Gelbtöne.
- **Indirekt/diffus**: LEDs rundum oben, zur Wand gerichtet oder hinter einem
  Diffusor (z. B. opakes/weißes Filament, Milchglasfolie). Direktes Licht
  erzeugt Glanzpunkte auf den Blättern.
- **Nicht dimmen** (oder nur mit flimmerfreien Treibern): gedimmte LEDs
  flackern und erzeugen Streifen im Handyfoto.
- Stromversorgung per USB (5 V) → Powerbank, Box bleibt mobil.

### Das Handy

- **Empfehlung: ein festes „Box-Handy"**, das immer in der Box bleibt.
  Verschiedene Handymodelle liefern unterschiedliche Farben – ein Gerät für alle
  Fotos macht die Daten deutlich vergleichbarer. Ein günstiges Android-Handy
  reicht völlig.
- **Android statt iPhone für die Box**: Auf dem iPhone lässt sich aus dem Browser
  heraus Belichtung und Weißabgleich nach aktuellem Stand nicht zuverlässig
  festhalten. Auf Android geht das eventuell direkt aus der Web-App, sonst mit
  der kostenlosen Kamera-App **Open Camera** (Belichtung, ISO und Weißabgleich
  sperrbar). Klärt der Pilot.
- Der Halter wird genau für dieses Modell gedruckt, Kameralinse mittig über dem
  Topf, Handy waagerecht.

### Grobe Kosten (ohne Handy)

Farbkarte ~60–80 €, LED-Streifen ~15–30 €, Platten ~20–40 €, Leisten/Profile
~20–40 €, Filament ~20 €, Diffusor ~5–10 €, USB-Netzteil ~10–20 €,
Magnete/Scharniere ~5 € → **ca. 150–250 €**. Gebrauchtes Android-Handy
zusätzlich ca. 80–150 €.

---

## 5. Die App (Software)

### Empfehlung: Web-App (PWA)

Eine Web-App ist eine Webseite, die sich wie eine App aufs Handy legen lässt.

**Vorteile:**
- läuft auf iPhone und Android
- kein App Store, kein Apple-Entwicklerkonto nötig
- kostenlos hostbar (z. B. GitHub Pages)
- Bildauswertung läuft direkt auf dem Handy, auch offline
- einfach zu ändern und zu verteilen (Link öffnen, fertig)

**Nachteil:** weniger Kontrolle über die Kamera (Belichtung/Weißabgleich lassen
sich im Browser, vor allem auf dem iPhone, kaum fest einstellen). Wird durch
Box + Referenzkarte ausgeglichen.

**Alternative: native App** (Flutter, Kotlin, Swift): volle Kamerakontrolle
(Belichtung, Weißabgleich, Fokus fixieren), aber deutlich aufwendiger in
Entwicklung, Verteilung und Pflege. Nur sinnvoll, falls sich die Web-App als
nicht präzise genug erweist.

### Ablauf für Mitarbeiter

1. Topf in die Box stellen, Abdeckscheibe drauf
2. Topf identifizieren: Etikett mit QR/EAN im Bild (wird aus dem Foto gelesen)
   oder Satz/Sorte aus einer Liste wählen
3. Foto auslösen
4. App zeigt Kontrollbild + Ergebnis (Fläche, % gelb, % braun, Note)
5. Bestätigen → gespeichert → nächster Topf

Geschätztes Tempo: ca. 10–20 Sekunden pro Topf. Eine reine Sicht-Bonitur ist mit
3–5 Sekunden schneller. Der Gewinn der App ist also nicht Tempo, sondern
**gleichbleibende Bewertung, Wachstumsmessung und ein Foto-Archiv**. Falls mehr
Tempo nötig ist: später mehrere Töpfe pro Foto (z. B. eine Palette mit festen
Plätzen).

### Daten

- **Anfang:** Speicherung auf dem Handy + Export als CSV/Excel
- **Wichtig:** Web-App „zum Startbildschirm hinzufügen" und am Ende jeder
  Sitzung exportieren (Excel + Fotos). Browser-Speicher allein ist kein sicheres
  Archiv.
- **Später:** zentrale Ablage (z. B. Online-Datenbank), damit alle Fotos und
  Ergebnisse an einem Ort landen
- In jeder exportierten Zeile steht die **Version der Auswertung**, damit
  Ergebnisse nach einer Änderung vergleichbar bleiben
- **Auswertung:** Befallsverlauf pro Satz/Sorte/Behandlung über die Zeit,
  z. B. als Kurve oder als AUDPC (Fläche unter der Befallsverlaufskurve – das
  übliche Maß in Pflanzenschutzversuchen)

---

## 6. Bonitur-Skala und Kalibrierung

- Die App liefert zuerst einen **stufenlosen Wert** (% befallene Blattfläche)
  und rechnet ihn in **eure bestehende Skala** um (z. B. 0–5, 1–9 oder
  Prozentklassen). Welche Skala ihr heute nutzt, bestimmt die Umrechnung.
  Falls ihr noch keine feste Skala habt: Die Skala von Ben Naim et al. (2025,
  *Planta*) für Basilikum-Mehltau definiert die Stufen über den Anteil
  befallener Blattfläche und passt daher gut zu einem Bild-Prozentwert.
- **Kalibrierung:**
  1. ca. 100–200 Töpfe über die ganze Bandbreite fotografieren (gesund bis
     stark befallen)
  2. jeden Topf zusätzlich von 1–3 erfahrenen Personen wie bisher bonitieren
  3. Grenzwerte der App so einstellen, dass App-Note und Menschen-Note möglichst
     gut übereinstimmen (Übereinstimmung messen, z. B. mit gewichtetem Kappa)
  4. neu prüfen bei neuer Sorte, neuer Saison, neuem Handy oder neuen LEDs
- Ein fester Satz von ca. 50 Referenzbildern mit bekannten Ergebnissen wird nach
  jeder Code-Änderung automatisch durchgerechnet. So fällt sofort auf, wenn eine
  Änderung die Ergebnisse verschiebt.
- Nebeneffekt: Menschen bonitieren untereinander oft unterschiedlich (bekanntes
  Problem, gerade bei geringem Befall). Die App ist dagegen immer gleich – das
  ist ein echter Vorteil.

---

## 7. Risiken und Gegenmaßnahmen

| Risiko | Gegenmaßnahme |
|---|---|
| Sichtbare Erde sieht aus wie braune Blätter | Abdeckscheibe über Erde und Topfrand; notfalls KI-Segmentierung |
| Junge Triebspitzen sind hellgrün und könnten als „gelblich" zählen | Grenzwerte im Pilot an echten Töpfen einstellen |
| Schatten zwischen Blättern wirken braun | diffuses Licht von allen Seiten; sehr dunkle Pixel ignorieren |
| Rote/violette Basilikumsorten | Farbschwellen funktionieren nicht → separat behandeln oder ausschließen |
| Glanzlichter auf (nassen) Blättern | diffuses Licht, nicht direkt nach dem Gießen fotografieren, Glanzpixel ignorieren |
| Unterschiedliche Pflanzenhöhe verändert die Fläche im Bild | für Vergleiche okay; bei Bedarf Höhe separat erfassen |
| Vergilbung durch andere Ursachen | App misst Vergilbung; Ursache muss bekannt sein |
| Früher/unterer Befall unsichtbar | im Pilot messen; falls zu groß: zweites, schräges Foto oder bei Sicht-Bonitur mit Foto-Archiv bleiben |
| Farbabweichungen zwischen Handys | ein festes Box-Handy mit gesperrten Kameraeinstellungen |

---

## 8. Fahrplan

**Phase 0 – Pilot (ohne eigene App, ca. 2 Wochen)**
- Karton-Box oder erste Box, gutes Licht, 24-Feld-Farbkarte, festes
  Android-Handy mit gesperrten Kameraeinstellungen, Topf-Etikett im Bild
- 100–200 Töpfe fotografieren, gesund bis stark befallen
- zwei Personen bonitieren jeden Topf wie bisher, inkl. Blick auf die
  Blattunterseite
- Auswertung mit einem Skript (PlantCV), zum Vergleich auch mit LeafScan
- **Ergebnis:** Klarheit, ob die Farbanalyse von oben bei euch gut genug mit der
  Sicht-Bonitur übereinstimmt, bevor Zeit in die App fließt. Falls nicht:
  digitale Sicht-Bonitur mit Referenzfotos und Foto-Archiv (siehe
  [RECHERCHE.md](RECHERCHE.md), Option 3)

**Phase 1 – Box + App-Grundgerüst (ohne Analyse)**
- Box final bauen (3D-Druck, LED, Farbkarte, Handyhalter, Abdeckscheibe)
- Web-App: Topf-ID, Sorte/Satz/Behandlung, manuelle Note mit Referenzfotos,
  Foto-Archiv, Excel-Export. Ist schon allein nützlich.

**Phase 2 – automatische Analyse**
- Farbkorrektur, Pflanzenerkennung, Farbklassen, Fläche in die App einbauen
  (Vorlage: LeafScan-Code, MIT-Lizenz)
- Umrechnung in eure Note mit den Pilot-Daten einstellen
- Verlaufsauswertung pro Satz/Sorte/Behandlung, zentrale Datenablage

**Phase 3 – optional**
- KI-Modell, falls Farbschwellen an Grenzen stoßen (Erde vs. Nekrose,
  aderbegrenzte Flecken als typisches Mehltau-Muster erkennen). Dafür sind die
  gesammelten Originalfotos aus Phase 1–2 die Trainingsdaten.
- native App, falls mehr Kamerakontrolle nötig ist

---

## 9. Offene Fragen

1. Welche Bonitur-Skala nutzt ihr aktuell (0–5, 1–9, % Blattfläche, …)?
2. Topfgröße und maximale Pflanzengröße (Durchmesser, Höhe) beim Fotografieren?
3. Nur grüne Sorten oder auch rote/violette?
4. Haben die Mitarbeiter iPhones oder Android? Ist ein festes Box-Handy möglich?
5. Wie viele Töpfe pro Bonitur-Durchgang (10, 100, 1000)? → Tempo und Ablauf
6. Wie werden Töpfe/Sätze identifiziert (Etikett, Tisch, Behandlung)?
7. Wo sollen die Ergebnisse landen (Excel, zentrale Datenbank, …)?
8. Geht es nur um Falschen Mehltau (Vergilbung) oder auch um Echten Mehltau
   (weißer, mehliger Belag)? Letzteres wäre als zusätzliche Kategorie „weiß"
   ebenfalls erkennbar.

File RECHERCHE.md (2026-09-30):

# Recherche: Selbst bauen oder fertige App nutzen?

Stand: 30.09.2026. Web-Recherche in fünf Bereichen (Handy-Apps, Desktop-/Open-Source-Software,
kommerzielle Systeme und Bonitur-Software, KI-Baukästen und Sprachmodelle, Vorarbeiten speziell zu
Basilikum-Mehltau). Jede Fundstelle wurde ein zweites Mal gegengeprüft: Gibt es sie noch, stimmt der
Preis, kann sie das Behauptete wirklich?

## Ergebnis

**Es gibt keine fertige App, die das kann.** Keine bezahlbare App und kein Dienst deckt alles ab: Foto
eines ganzen Topfs von oben, Anteil grün/gelb/braun, Pflanzengröße, eigene Boniturskala, Topf-IDs und
Excel-Export. Auch speziell für Basilikum-Mehltau wurde weder ein Werkzeug noch ein veröffentlichtes
Bildverfahren gefunden.

**Empfehlung: selbst bauen, aber in Etappen und mit vorhandenen Gratis-Bausteinen.** Der Kern (Farben
korrigieren, Pixel nach Farbe einteilen, zählen) ist einfach, braucht keine KI und ist in anderen
Kulturen erprobt, z. B. bei Gurken-Mehltau.

## Was es gibt – und warum es nicht reicht

| Lösung | Was sie kann | Warum sie nicht reicht | Kosten | Stand 2026 |
|---|---|---|---|---|
| [LeafScan](https://leonlenzo.github.io/leaf-scan/) (Browser, Curtin Univ.) | gesund / chlorotisch / nekrotisch in %, CSV-Export | Forschungsprototyp für einzelne Weizenblätter; Erde und Topf würden als „braun" gezählt; kein Maßstab, keine Topf-IDs, technische Schieberegler | gratis, MIT-Lizenz (Code darf wiederverwendet werden) | neu, aktiv (v1.0 Aug. 2026) |
| [Petiole Pro](https://petiole.pro/) (Android + Desktop) | Blattfläche, Grünindizes, Nekrose (auf dem Handy von Hand umrandet) | gebaut für Einzelblätter auf Kalibrierplatte; keine automatische Gelb/Braun-Einteilung, keine Topf-IDs | App gratis mit Abo-Funktionen; Desktop und Service nur auf Anfrage | aktiv |
| [Leaf Doctor](https://apps.apple.com/gb/app/leaf-doctor/id874509900) (iOS) | % krankes Gewebe | letztes Update 2017, Android-Version weg; jedes Bild von Hand einstellen; nur krank/gesund; keine Größe, kein Export außer E-Mail | gratis | nicht mehr gepflegt |
| Easy Leaf Area, Canopeo, Field Book „Canopy Cover" | grüne Fläche / Bodenbedeckung | zählen nur **grüne** Pixel – gelbe und braune Blätter fallen einfach raus | gratis | Canopeo aufgegeben, andere gepflegt |
| Plantix, PlantVillage, Agrio u. ä. | erkennen, **welche** Krankheit | messen nicht, **wie stark**; Basilikum-Mehltau nicht bestätigt | gratis / Abo | aktiv |
| [PlantCV](https://plantcv.org/) (Python, Danforth Center) | Farbkarten-Korrektur, Pixelklassen, Flächen, Stapelverarbeitung | Programmierbibliothek, keine App für Mitarbeiter | gratis, MPL-2.0 | sehr aktiv |
| ImageJ/Fiji, ilastik | Farbschwellen bzw. lernende Pixelklassifikation am PC | braucht jemanden, der Makros bzw. Klassifikatoren einrichtet; keine Handy-Erfassung | gratis | aktiv |
| APS Assess 2.0 | klassische Befallsschätzung über Farbe | alte 32-Bit-Windows-Software, ein Bild nach dem anderen | ca. 270–540 USD | kein Update |
| LemnaTec, Phenospex, PSI | Profi-Phänotypisierung, könnte es technisch | Zehntausende bis Hunderttausende Euro, für Forschungslabore | nur auf Anfrage | aktiv |
| Gewächshaus-KI (IUNU, Ecoation, HortiKey) | Überwachung ganzer Hightech-Gewächshäuser | Schienen/Kameras, Fokus auf Gemüse, keine Bonitur pro Topf | Enterprise, auf Anfrage | teils unsicher (Umstrukturierungen) |
| Bonitur-Software (PIAF, ARM, smatrix) | Versuchsdaten, Bonitur-Erfassung, Auswertung | **keine** Bildanalyse | auf Anfrage bzw. smatrix 93 €/Nutzer/Monat | aktiv |
| Erfassungs-Apps ([Field Book](https://github.com/PhenoApps/Field-Book), [GridScore](https://github.com/cropgeeks/gridscore-next-client), ODK/Kobo, AppSheet) | Formulare, Barcodes, Export | keine Bildanalyse | gratis bis ca. 10 $/Nutzer/Monat | aktiv |
| KI-Baukästen (Roboflow, Teachable Machine, Edge Impulse) | eigene Bildmodelle trainieren | brauchen Hunderte bewertete Bilder; meist nur „Bild → Klasse", keine Flächenanteile | gratis bis Abo | aktiv, Preise ändern sich oft |
| Sprachmodelle mit Bildverständnis (Claude, GPT, Gemini) als Bewerter | Foto beschreiben, grob einschätzen | Studien zeigen große Schwankungen: dasselbe Foto bekommt verschiedene Noten, und nach Modell-Updates ändert sich die Bewertung. Für eine messbare Note ungeeignet | ca. 0,1–1 Cent pro Bild | aktiv |

## Vorarbeiten aus der Forschung

- **Basilikum-Mehltau:** kein Bildverfahren veröffentlicht, nur visuelle Skalen. Die meisten
  (z. B. Rutgers 0–4) bewerten den Sporenrasen auf der **Blattunterseite**, den eine Kamera von oben
  nicht sieht.
- **Passende Skala:** Ben Naim, Cohen, Wyenandt, Simon u. a. (2025, *Planta*,
  [PMC12122581](https://pmc.ncbi.nlm.nih.gov/articles/PMC12122581/)): Disease Intensity 0–4. Die
  Stufen 1–3 sind über den **Anteil befallener Blattfläche** definiert (bis 10 %, bis 25 %, bis 50 %)
  und lassen sich deshalb gut mit einem Bild-Prozentwert abgleichen. Deutsche Praxisskalen: LVG
  Heidelberg 0–3, HSWT 1–9.
- **Methode anderswo erprobt:** Bei Gurken-Mehltau stimmte die Pixelanteil-Methode sehr gut mit
  Experten überein. Das waren aber Einzelblätter, keine ganzen Töpfe von oben – die Werte lassen sich
  nicht 1:1 übertragen.
- **Warnung aus mehreren Studien:** Ohne kontrolliertes Licht und Farbkarte funktionieren
  Farbmessungen nicht zuverlässig. Das bestätigt die Idee mit der Box.

## Optionen im Vergleich

1. **Eigene Web-App, in Etappen (empfohlen)**
   - Etappe 0: Pilot ohne eigene App (siehe unten)
   - Etappe 1: Erfassungsteil – Topf-ID, Sorte/Satz/Behandlung, manuelle Note mit Referenzfotos,
     Foto-Archiv, Excel-Export. Schon allein nützlich.
   - Etappe 2: automatische Farbanalyse dazu; als Vorlage dient der LeafScan-Code (MIT-Lizenz).
   - Kosten: Hardware ca. 150–250 €, Hosting 0 €.
2. **Handy fotografiert, PC wertet aus:** Fotos landen in einem Ordner, ein PlantCV-Skript erstellt
   daraus eine Excel-Tabelle. Farbtechnisch am robustesten; Ergebnis aber erst später am PC statt
   direkt an der Box. Rückfalloption und gute Referenz, um Option 1 zu prüfen.
3. **Nur digitale Sicht-Bonitur:** Handy-Formular mit Referenzfotos pro Notenstufe, Fotos nur zur
   Dokumentation. Billigste und schnellste Variante. Braucht es ohnehin als Vergleichsbasis – und
   ist die Antwort, falls der Pilot zeigt, dass die Kamera von oben zu viel verpasst.
4. **Fertige Apps (LeafScan, Leaf Doctor, Easy Leaf Area):** nur für den Pilot-Test brauchbar,
   nicht für den Alltag.
5. **KI-Baukästen, App-Baukästen, Sprachmodelle als Bewerter:** zweites System, laufende Kosten,
   Analyse trotzdem nicht gelöst bzw. nicht reproduzierbar. Höchstens als späte Ergänzung.
6. **Profi-Systeme:** weit über Budget.

## Pilot (Etappe 0)

- 100–200 Töpfe über die ganze Befallsbandbreite in einer Box (anfangs auch Karton) fotografieren
- festes Android-Handy, Farbkarte und Topf-Etikett im Bild
- zwei Personen bonitieren jeden Topf wie bisher, inkl. Blick auf die Blattunterseite
- Auswertung mit einem Skript (PlantCV) bzw. zum Vergleich mit LeafScan
- **Entscheidung:** Stimmt der Bildwert (% gelb + braun, Fläche) gut genug mit der Note der Menschen
  überein? Übereinstimmung messen, z. B. mit gewichtetem Kappa.
- Größtes erwartetes Problem: Befall an den unteren Blättern ist von oben nicht sichtbar.

## Was ein Selbstbau braucht, damit er langfristig funktioniert

- Code im Git-Repository (dieses Repo)
- fester Satz von ca. 50 Referenzbildern mit bekannten Ergebnissen, der nach jeder Änderung
  automatisch geprüft wird
- Algorithmus-Version in jeder exportierten Zeile
- Originalfotos immer archivieren, damit man sie später neu auswerten kann
- Web-App auf dem Handy „zum Startbildschirm hinzufügen" und am Ende jeder Sitzung exportieren –
  Browser-Speicher allein ist kein sicheres Archiv

## Nicht bestätigt / offen

- Ob eine Web-App auf dem Android-Handy Belichtung und Weißabgleich selbst festhalten kann (auf dem
  iPhone vermutlich nicht). Falls nicht: die Kamera-App Open Camera mit festen Einstellungen
  verwenden. Klärt der Pilot.
- Preise von Petiole Pro (Desktop/Service), PIAF und ARM sind nicht öffentlich.
- Möglicher Partner für die Validierung: die LVG Heidelberg hat Versuche zu Basilikum-Mehltau an
  Topfbasilikum gemacht. Ob eine Zusammenarbeit möglich ist, wurde nicht geprüft.

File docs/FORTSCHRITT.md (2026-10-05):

# Fortschritt

Stand: 05.10.2026. Alle Bausteine sind **vorab gebaut und mit künstlichen Fotos getestet**
(automatische Tests und Browser-Durchläufe). Was noch fehlt, braucht echte Hardware, echte
Fotos oder Entscheidungen des Inhabers – das steht je Baustein unter „Offen“.

Legende: ✅ gebaut und getestet · 🟡 gebaut, Prüfung mit echter Box/echten Fotos offen · ⬜ offen

| Nr. | Baustein | Stand | Offen |
|---|---|---|---|
| B1 | Analyse-Kern und automatische Tests | 🟡 | Referenzbilder (Etappe 3) ins Repository, Sollwerte erzeugen, 4 Beispiel-Kontrollbilder echter Töpfe in `docs/beispiele/` |
| B2 | Analyse-Werkstatt | 🟡 | mit 5–10 echten Pilotfotos und der Pilot-Excel am Firmen-PC prüfen |
| B3 | App-Grundgerüst, Hosting, offline | 🟡 | Hauptzweig in `main` umbenennen, GitHub Pages einschalten (Quelle: GitHub Actions), App auf dem Box-Handy installieren, Flugmodus-Test |
| B4 | Sitzungen und Stammdaten | 🟡 | Neustart-Test am Box-Handy |
| B5 | Aufnahme, Foto-Import, Foto-Archiv | 🟡 | 10 Fotos aus Open Camera importieren; Hilfslinien in der Box prüfen; Kamera-Test-Seite am Box-Handy (Ergebnis ins Projekttagebuch) |
| B6 | Analyse in der App (+ No-Go-Variante Sicht-Bonitur) | 🟡 | Einstellungsdatei aus Etappe 4; App und Werkstatt mit 5 Referenzbildern vergleichen; Dauer am Box-Handy |
| B7 | QR-Etiketten drucken und lesen | 🟡 | 10 gedruckte Karten im Etikettenhalter fotografieren: alle 10 IDs gelesen? |
| B8 | Export und Datensicherung | 🟡 | Export einer Test-Sitzung (10 Töpfe) am Firmen-PC in Excel öffnen; Teilen an den Cloud-Ordner am Box-Handy ausprobieren |
| B9 | Einstellungen, Übersicht, Verlauf, AUDPC | 🟡 | PIN am Handy festlegen; Kontroll-Pflanze wöchentlich |

## Geplant: Vereinfachung auf den Versuchs-Ablauf (wartet auf OK)

Der Inhaber nutzt das Werkzeug vor allem bei **Versuchen**: Versuch planen, an jedem Termin
fotografieren, Befall % und Note sofort sehen, am Ende ein Excel als Versuchsdaten. Plan
(Einzelheiten in `docs/So_geht_es_weiter.pdf`, Kapitel 2 und 4):

- Start mit Versuchen statt Sitzungen; Versuch = Name, Varianten (A, B, C …), Töpfe je Variante
  → Topf-Nummern A1–A10 … (QR-Karten wahlweise).
- Vor dem Foto „Was wird fotografiert?“ – nächster Topf vorgeschlagen, QR-Code prüft mit.
- Ergebnis groß: Befall % und Note, dann „Weiter“. „Schnell messen“ ohne Versuch.
- Ein Excel je Versuch über alle Termine: Blätter „Messwerte“, „Übersicht“ (Mittel je Variante
  und Termin), „Versuch“; Fotos als ZIP mit Namen wie `2026-10-12_A4.jpg`.
- Kein Dashboard in der App; Übersicht/AUDPC/Regelkarte nur noch im Excel bzw. versteckt.
- Probelauf-Modus (ca. 50 Töpfe): Noten blind in der App, App-Ergebnis erst danach.
- Fotobox: Vorschlag fertiges LED-Lichtzelt (≥ 70–80 cm, Öffnung oben, CRI ≥ 90) statt Eigenbau.

## Was es schon gibt

**B1 Analyse-Kern** (`kern/`): Verkleinern auf 1600 Pixel (lange Kante), Farbkorrektur mit allen
24 Feldern (3×3-Matrix in linearem RGB, Sollwerte ColorChecker ab Nov. 2014, Restfehler ΔE2000),
Auswertekreis, HSV, Pflanzenmaske mit Fleckenfilter, Klassen grün/gelb/braun, Glanzlichter,
Kennzahlen (`flaeche_px`, `flaeche_cm2_ca`, `gruen_pct`, `gelb_pct`, `braun_pct`, `befall_pct`,
`gruenwert`), Note über die Notentabelle, Kontrollbild, Qualitätschecks (Farbkarte, Helligkeit,
Kreis, keine Pflanze). Statistik: gewichtetes Kappa, Spearman, Standardabweichung, AUDPC.
Tests mit künstlichen Fotos (bekannte Anteile, Farbstich, Unterbelichtung, QR) und den
Rechenbeispielen des Leitfadens.

**B2 Analyse-Werkstatt** (`werkstatt/`, als Einzeldatei `dist/analyse-werkstatt.html`):
Fotos + Pilot-Excel laden, Einrichten (Farbkarte mit 24 Messquadraten, Topfkreis, Etikett,
Maßstab), Zuordnung über `foto_datei` mit QR-Rückfall, Auswertung, Kontrollbilder (sortiert nach
Abweichung), Streudiagramm, Kappa A–B/App–A/App–B, Spearman, Wiederholbarkeit, Lichttest,
Farbkarten-Quote, unsichtbarer Befall, Regler mit sofortiger Wirkung, Kalibrier-Modus
(Übungs-/Prüfhälfte, Vorschlag für Notengrenzen), Go/No-Go nach Tabelle 8.2, Export
(Ergebnis-Excel, Kontrollbilder-ZIP, Einstellungsdatei, Referenzbilder-Paket). Demo mit
künstlichem Pilot (71 Fotos) zum Ausprobieren.

**B3–B9 Handy-App** (`app/`): installierbar, offline, Hinweis bei neuer Version,
Speicheranzeige, dauerhafter Speicher. Sitzungen (Bonitur, Kontroll-Pflanze, Kalibrierung) mit
Stammdaten (auch als Excel). Foto-Import (mehrere auf einmal, Original unverändert) oder
Direktaufnahme mit Hilfslinien; Kamera-Test (Fähigkeiten, feste Werte, 5 Testfotos, Urteil).
Ergebnis mit Kontrollbild, Kennzahlen, Note, Warnungen, Topf-ID aus dem QR-Code, Hand-Note.
Sicht-Bonitur mit Referenzfotos (No-Go-Variante). Export als Excel + ZIP, Teilen, Löschen erst
nach bestätigter Sicherung. Einstellungen mit PIN, Schwellen/Notentabelle mit Kennung und
Änderungsprotokoll, Einrichten am Handy (Farbkarte, Topfkreis, Etikett, Maßstab). Übersicht je
Satz/Behandlung mit Verlauf und AUDPC, Regelkarte der Kontroll-Pflanze. Testversion unter
`/vorschau/` mit eigenen Daten.

**B7 Druckseite** (`etiketten/`) und **Vorlagen** (`vorlagen/`): Topf-Karten P001–P200,
Maßstab-Karte, Pilot-Excel mit Auswahllisten, Bonitur-Bogen.

**GitHub Actions**: Tests bei jedem Push/Pull Request (Rechnung und kompletter Ablauf im
Browser); Veröffentlichung auf GitHub Pages (nur App, Werkstatt, Kern, Bibliotheken,
Druckseite, Vorlagen).

## Etappen (Leitfaden Kapitel 2)

| Etappe | Inhalt | Stand |
|---|---|---|
| 0 | Entscheidungen, Material | ⬜ Entscheidungen des Inhabers offen (siehe Fragen-PDF) |
| 1 | Fotobox bauen | ⬜ Druckteile vorbereitet (`fotobox/`), Maße fehlen |
| 2 | Box-Handy einrichten | ⬜ |
| 3 | Pilot: Fotos und Sicht-Bonitur | ⬜ Vorlagen fertig |
| 4 | Pilot auswerten (Werkstatt) | ⬜ Werkstatt fertig |
| 5 | Handy-App | 🟡 vorab gebaut |
| 6 | Kalibrieren | ⬜ Werkzeuge fertig (Kalibrier-Modus, Kontroll-Pflanze) |
| 7 | Betrieb | ⬜ |

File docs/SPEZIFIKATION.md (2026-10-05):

# Spezifikation: Mehltau-Bonitur per Handy

Verbindliche Zahlen, Entscheidungen und technische Vorgaben für das Projekt.
Claude liest diese Datei vor jeder Arbeit. Grundlage ist der Leitfaden
`docs/Leitfaden_Mehltau-Bonitur.pdf`; bei Abweichungen gilt diese Datei.
Änderungen an Zahlen und Grenzwerten immer hier eintragen, mit Datum.

Stand: 05.10.2026

---

## Regeln für die Arbeit an diesem Projekt

- Der Projektinhaber programmiert nicht. Erklärungen in einfachem Deutsch, ohne
  Fachbegriffe oder mit kurzer Erklärung.
- Kleine Schritte: ein Baustein (B1–B9) pro Sitzung, danach Pull Request.
- Keine echten Betriebsdaten ins Repository, außer den Referenzbildern in
  `referenzbilder/` (mit `referenzbilder.xlsx`). Personen nur als Kürzel.
- Ausgabe der App heißt immer „sichtbare Symptome (von oben)“, keine
  Mehltau-Diagnose.
- Jede Änderung, die Ergebnisse verschieben kann (Rechenweg, Schwellwerte,
  Notentabelle), erhöht die Algorithmus-Version und wird hier eingetragen.

---

## Entscheidungen Etappe 0

*Noch offen – wird in Etappe 0 ausgefüllt (Leitfaden Kapitel 3).*

| Punkt | Entscheidung | Datum |
|---|---|---|
| Boniturskala | – | – |
| Box-Handy (Modell, Android-Version) | – | – |
| Sorten im Pilot (nur grüne) | – | – |
| Topf- und Pflanzenmaße A–G (cm) | – | – |
| Repository öffentlich/privat, Hosting | – | – |
| Pilot-Bonitur: Person A / B (Kürzel), Zeitraum | – | – |
| Datenablage (Ort, Hauptordner) | – | – |

Maße A–G: A Topf oben (Außenkante Rand) · B Topf unten · C Topfhöhe (ca. 11) ·
D größter Pflanzendurchmesser (bis ca. 25) · E Pflanzenhöhe über Topfrand
(bis ca. 25) · F Tisch bis höchste Blattspitze (bis ca. 36) · G Stängel-Büschel
über der Erde (Loch Abdeckscheibe ca. 3). Prüfung: 70 cm − F muss größer als D sein.

---

## Projektüberblick

Topfbasilikum mit Falschem Mehltau (*Peronospora belbahrii*). Topf in eine
Fotobox mit festem Licht, Foto von oben mit einem festen Android-Handy. Die
Software misst Pflanzenfläche und Anteil grün/gelb/braun, berechnet Befall %
und eine Note und exportiert alles nach Excel.

Befall beginnt laut Beratungsliteratur an den unteren Blättern; die Kamera
sieht ihn von oben spät. Vergilbung kann andere Ursachen haben. Rote/violette
Sorten werden nicht unterstützt.

### Etappen

| Etappe | Leitfaden | Inhalt | grobe Dauer |
|---|---|---|---|
| 0 | Kap. 3 | Vorbereitung & Entscheidungen | ca. 1 Woche |
| 1 | Kap. 4 | Fotobox bauen (erst Karton, dann fest) | 1–3 Wochen |
| 2 | Kap. 5 | Box-Handy einrichten | 1 Tag |
| 3 | Kap. 6 | Pilot: Fotos + Sicht-Bonitur, 100–200 Töpfe | 1–2 Wochen |
| 4 | Kap. 8 | Pilot auswerten (Analyse-Werkstatt), Go/No-Go | ca. 1 Woche |
| 5 | Kap. 9 | Handy-App bauen, Bausteine B3–B9 | 3–6 Wochen |
| 6 | Kap. 10 | Kalibrieren & prüfen, 100–200 neue Töpfe | 2–4 Wochen |
| 7 | Kap. 11 | Betrieb | laufend |

Reihenfolge: Das Risiko (funktioniert die Farbauswertung von oben?) wird zuerst
geprüft. B1 (Analyse-Kern) und B2 (Analyse-Werkstatt) entstehen für Etappe 4;
die Handy-App nutzt denselben Kern. Bei No-Go wird die Handy-App ohne
automatische Analyse gebaut (digitale Sicht-Bonitur mit Referenzfotos je
Notenstufe, Foto-Archiv, Excel-Export).

---

## Boniturskala

Eigene Skala des Betriebs, falls vorhanden. Sonst Vorschlag 0–4, angelehnt an
Ben Naim et al. 2025 (*Planta*):

| Note | Bedeutung |
|---|---|
| 0 | keine sichtbaren Symptome |
| 1 | bis 10 % der Blattfläche befallen |
| 2 | über 10 bis 25 % |
| 3 | über 25 bis 50 % |
| 4 | über 50 % oder starke Nekrosen |

---

## Fotobox

- Innenmaß 50 × 50 cm, Höhe 70 cm. Handy liegt auf dem Deckel, Hauptkamera (1×)
  ca. 70 cm über dem Boden, genau über der Topfmitte. Faustregel: Abstand ≈
  Bildbreite an der kurzen Bildseite.
- Rahmen: Holzleisten 20 × 20 mm oder Alu-Profil 2020; 4 × 70 cm, 8 × 46–50 cm;
  8 gedruckte Eckverbinder.
- Wände und Deckel matt weiß (Forex 3–5 mm oder Kapa 5 mm), Vorderwand als
  Klappe (Magnete/Scharniere). Boden matt schwarz oder dunkelgrau.
- Deckel mit Kameraloch ca. 3 cm, gedruckter Handyhalter für genau das Box-Handy.
- 3D-Druckteile (OpenSCAD, parametrisch): Eckverbinder, Handyhalter,
  LED-/Diffusor-Halteleisten, Zentrierring (Maß B), Abdeckscheibe (matt schwarz,
  Durchmesser A + ca. 1 cm, Schlitz bis zur Mitte, Mittelloch ca. 3 cm),
  Farbkarten-Halter (flach, parallel zur Kamera, Bodenecke), Etikettenhalter
  (Schlitz für die Topf-Karte, gegenüberliegende Ecke).
- Licht: 5-V-USB-LED-Streifen, CRI/Ra ≥ 90, 5000–6500 K, ca. 2 m, rundum oben,
  indirekt oder hinter Diffusor. Nicht dimmen.
- Farbkarte: 24 Felder, Calibrite ColorChecker Classic Mini. Karten ab Nov. 2014
  haben neue Sollwerte (Herstellerdaten verwenden).
- Maßstab-Karte: 10 × 10 cm, matt, auf Sockel in typischer Blatthöhe, einmal
  fotografiert → „Pixel je cm²“ (nur ungefähre cm²).
- Kosten ca. 150–250 € ohne Handy; gebrauchtes Handy ca. 80–150 €.

---

## Box-Handy

- Android 10 oder neuer, Hauptkamera ≥ 12 MP, aktueller Chrome, Open Camera muss
  „Camera2-API“ anbieten. Kein iPhone (Open Camera nur Android; Browser kann dort
  Belichtung/Weißabgleich nicht sicher festhalten).
- Open Camera (Leitfaden Tabelle 5.1): Camera2-API · Foto-Modus Standard, ohne
  Blitz · Weißabgleich manuell (Kelvin passend zu den LEDs, z. B. 5500) · ISO fest
  (z. B. 100) · Verschlusszeit fest · Fokus manuell oder gesperrt · ca. 8 MP, 4:3
  (z. B. 3264 × 2448) · JPEG 95 %, kein RAW · Timer 2 s oder Lautstärketaste ·
  Speicherort `DCIM/Bonitur`, Präfix `BOX_` (Dateiname `BOX_JJJJMMTT_hhmmss.jpg`)
  · Ausrichtung Querformat gesperrt · Auto-Level, Gesichtserkennung, Stempel,
  Geotagging aus.

---

## Pilot

- 100–200 Töpfe, je Notenstufe mind. 15–20 (Note 0: 20–40).
- Zwei Personen bonitieren unabhängig: Note, geschätzter Befall %, Sporenrasen
  auf der Blattunterseite ja/nein. Pflanzen trocken fotografieren, keine Blätter
  entfernen.
- Topf-Karte mit groß gedruckter Nummer (später QR) im Etikettenhalter im Bild.
- `pilot_bonitur.xlsx`:
  - Blatt „Bonitur“: `topf_nr`, `datum`, `sorte`, `satz`, `behandlung`,
    `note_A`, `note_B`, `prozent_A`, `prozent_B`, `sporen_unten`, `foto_datei`,
    `bemerkung`
  - Blatt „Wiederholung“: `topf_nr`, `durchgang` (1–5), `foto_datei`, `bemerkung`
  - Blatt „Lichttest“: `topf_nr`, `zeitpunkt` (morgens/mittags/abends),
    `hallenlicht` (an/aus), `foto_datei`, `bemerkung`
- Wiederholbarkeit: 5 Töpfe je 5× (jedes Mal herausnehmen, neu einsetzen).
  Lichttest: 1 Topf morgens/mittags/abends, Hallenlicht an/aus (6 Fotos).
- Referenzbilder: ca. 45–55 Fotos (je Notenstufe 4–6 + 25 Wiederholungsfotos)
  in `referenzbilder/`, dazu `referenzbilder.xlsx` (Blätter „Bonitur“ und
  „Wiederholung“). Alle anderen Pilotfotos bleiben auf dem Firmen-PC.
- Ordner beim Betrieb: `Bonitur/Pilot/` (Excel), `Bonitur/Pilot/fotos/JJJJ-MM-TT/`,
  `Bonitur/Pilot/referenzbilder/`, `Bonitur/Kalibrierung/`,
  `Bonitur/JJJJ/JJJJ-MM-TT_SatzNN/`, `Bonitur/Auswertungen/`.

---

## Analyse

Startwerte, werden im Pilot eingestellt.

1. Bild auf ca. 1600 Pixel lange Kante verkleinern.
2. Farbkorrektur: Farbkarten-Position einmal eingestellt (4 Ecken). Mittelwert
   der 24 Felder (Feldmitte) → 3×3-Farbmatrix per Ausgleichsrechnung auf die
   Sollfarben → auf das ganze Bild. Qualität: mittlere Restabweichung ΔE2000;
   Warnung „Farbkarte prüfen“ über 6, „Farbkarte nicht gefunden“ über 12
   (festgelegt 05.10.2026).
3. Auswertekreis um die Topfmitte (einmal eingestellt).
4. HSV: Farbton H 0–360°, Sättigung S 0–1, Helligkeit V 0–1.
5. Pflanzen-Maske: H 15–170°, S ≥ 0,20, V ≥ 0,15. Glanzlicht (V > 0,90 und
   S < 0,15) ignorieren. Kleine Einzelflecken entfernen: zusammenhängende Gebiete
   unter 30 Pixeln (im 1600-Pixel-Bild, 8er-Nachbarschaft) (festgelegt 05.10.2026).
6. Klassen: grün H ≥ 80° · gelb 45–80° · braun 15–45°.
7. Kennzahlen: `flaeche_px`, `flaeche_cm2_ca` (über Maßstab-Karte), `gruen_pct`,
   `gelb_pct`, `braun_pct`, `befall_pct` = gelb + braun, `gruenwert` (mittlerer
   Farbton in Grad), `note_app`.
8. Umrechnungstabelle (Startwerte, Skala 0–4): 0 unter 2 % · 1: 2–10 % ·
   2: über 10–25 % · 3: über 25–50 % · 4: über 50 %.
9. Kontrollbild: Foto mit eingefärbten Klassen (grün/gelb/braun), Warnungen.
10. Qualitätschecks: Farbkarte gefunden & ΔE ok · Belichtung ok · Pflanze gefunden
    (Mindestfläche) · Topf-ID gelesen.

Technik: reines JavaScript im Browser, keine Installation. Bibliotheken lokal
im Repository: jsQR (QR lesen), SheetJS (Excel), JSZip (ZIP). Ideen aus
LeafScan (MIT-Lizenz) dürfen genutzt werden. Algorithmus-Version beginnt bei
`A-1.0`.

### Umsetzung A-1.0 (festgelegt von Claude, 05.10.2026)

- Verkleinern im Kern selbst (flächengewichtet, lange Kante 1600 Pixel), nicht im
  Browser – App, Werkstatt und Tests rechnen dadurch exakt gleich.
- Farbkorrektur: Sollwerte ColorChecker Classic ab Nov. 2014 (Lab D50, Bradford
  nach D65). Je Feld der Mittelwert der inneren 28 % (Raster 9 × 9 Punkte),
  übersteuerte Felder werden ausgelassen, Graufelder doppelt gewichtet,
  mindestens 6 Felder. Reihenfolge der 4 Ecken wird bei Bedarf automatisch
  korrigiert.
- Farbton in ganzen Grad, S und V in ganzen Prozent. Die Regler der Werkstatt
  bleiben in festen Bereichen (Farbton 10–180°, S 10–50 % in 2er-Schritten,
  V 10–35 %); innerhalb dieser Bereiche ist die schnelle Neuberechnung über
  Histogramme exakt. Der Fleckenfilter arbeitet auf der lockersten
  Reglerstellung (H 10–180°, S ≥ 10 %, V ≥ 10 %).
- Weitere Qualitätschecks: Weißfeld der Farbkarte (unkorrigiert) unter 120 →
  „Bild zu dunkel“, über 250 → „Bild zu hell“; Pflanzenfläche unter 2 % des
  Auswertekreises → „Keine Pflanze gefunden“; fehlende Einstellung → Warnung.
- `gruenwert` = mittlerer Farbton aller Pflanzenpixel in Grad.
- `flaeche_cm2_ca` = `flaeche_px` / Pixel je cm² der Maßstab-Karte (gemessen an
  den 4 äußeren Ecken des schwarzen 10-cm-Quadrats, im 1600-Pixel-Bild).
- Kontrollbild: außerhalb des Kreises abgedunkelt; grün, gelb, rot (= braun),
  hellblau (= Glanzlicht) halbdeckend über dem farbkorrigierten Foto.
- Einstellungsdatei (JSON, Format 1): Farbkarten-Ecken, Auswertekreis,
  Etikettbereich (alles relativ zur Bildgröße), Maßstab, Schwellen,
  Notentabelle, Qualitätsgrenzen, Betriebsart, Kennung und Änderungsprotokoll.
  Kennung: Werkstatt `W1`, `W2` …, Handy `W3.H1`, `W3.H2` …; jede Ergebniszeile
  trägt `algorithmus_version` = Rechenweg/Kennung, z. B. `A-1.0/W3.H1`.
- Topf-ID: QR-Code (Fehlerkorrektur M) in voller Auflösung im Etikettbereich
  (+25 % Rand) lesen, sonst im ganzen Bild (verkleinert auf 2000 Pixel).

---

## Analyse-Werkstatt

Webseite im PC-Browser (Chrome/Edge). Ordner mit Fotos + Bonitur-Excel wählen,
alles wird lokal ausgewertet (Fotos verlassen den PC nicht). Einrichtung:
4 Ecken der Farbkarte, Auswertekreis, Maßstab-Karte. Ergebnis: Ergebnis-Excel,
Kontrollbilder, Streudiagramm (App-Befall % gegen Menschen-Note),
Übereinstimmung (gewichtetes Kappa, Spearman), Wiederholbarkeit, „unsichtbarer
Befall“, Regler für die Schwellwerte mit sofortiger Wirkung. Einstellungen
lassen sich als Einstellungsdatei speichern und in der App laden.

---

## Go/No-Go

Vorschlag. Kappa = quadratisch gewichtetes Kappa. Kappa App–Menschen = Mittel
aus Kappa App–A und App–B.

- **GO:** Kappa App–Menschen ≥ 0,6 · höchstens 0,1 unter Kappa A–B · Streuung
  (Standardabweichung) von Befall % bei den 5×-Fotos ≤ 2 Prozentpunkte je Topf ·
  Farbkarte in ≥ 95 % der Fotos erkannt.
- **NACHBESSERN:** Kappa 0,4–0,6, Wiederholbarkeit schlecht, beim ersten
  Durchgang auch Kappa unter 0,4, oder Go knapp verfehlt → Licht, Abdeckscheibe,
  Schwellen, evtl. Schrägfoto; Teil-Pilot mit 30–50 Töpfen.
- **NO-GO:** Kappa unter 0,4 auch nach Nachbessern, oder zu viele Töpfe mit
  Sporen unten, aber App-Befall unter 1 % (Grenze vorher festlegen) → Handy-App
  ohne automatische Analyse.

---

## Handy-App

- PWA: HTML/CSS/JavaScript, offline nach dem ersten Öffnen, kein App Store.
- Hosting: GitHub Pages (kostenlos bei öffentlichem Repository; bei privatem
  Repository kostenpflichtiges GitHub-Abo). Alternativen: Cloudflare Pages,
  Netlify. HTTPS nötig für die Kamera.
- Bildschirme: (1) Start – Sitzung starten (Datum, Kürzel, Satz/Versuch), frühere
  Sitzungen, Export · (2) Aufnahme – Kamera-Vorschau mit Hilfslinien oder
  Foto-Import aus Open Camera · (3) Ergebnis – Kontrollbild, Kennzahlen, Note,
  Topf-ID (änderbar), Warnungen, Speichern/Wiederholen · (4) Übersicht – Tabelle,
  Mittelwerte je Satz/Behandlung, Verlauf · (5) Export – Excel + ZIP,
  Sicherungs-Erinnerung · (6) Einstellungen (geschützt) – Farbkarte,
  Auswertekreis, Schwellwerte, Notentabelle, QR-Etiketten, Versionen.
- Speicherung in IndexedDB, dauerhafter Speicher anfordern. Fotos erst nach
  bestätigtem Export löschen.
- Datenfelder je Messung (Excel-Spalten): `mess_id`, `datum_zeit`, `mitarbeiter`,
  `sitzung_id`, `topf_id`, `satz`, `sorte`, `behandlung`, `tisch`, `foto_datei`,
  `flaeche_px`, `flaeche_cm2_ca`, `gruen_pct`, `gelb_pct`, `braun_pct`,
  `befall_pct`, `gruenwert`, `note_app`, `note_manuell`, `qualitaet`,
  `algorithmus_version`, `app_version`, `handy_modell`, `bemerkung`.
- Versionen: `app_version` zählt jede Änderung; `algorithmus_version` nur
  Änderungen, die Ergebnisse verschieben können.
- Umsetzung (05.10.2026): `mess_id` = `sitzung_id`-Laufnummer (z. B.
  `2027-02-10_Satz12-007`); `sitzung_id` = Datum_SatzNN, bei Kontroll-Pflanze
  Datum_Kontrolle, bei Kalibrierung Datum_Kalibrierung; zweite Sitzung am selben
  Tag mit `_2`. Export: `2027-02-10_Satz12.xlsx` (Blätter „Messungen“ und
  „Sitzung“ mit Versionen und Einstellungen) und `2027-02-10_Satz12.zip`
  (Excel, `fotos/` unverändert, `kontrollbilder/`, `einstellungen.json`).
  Sicht-Bonitur (No-Go-Variante): Analysefelder leer, Note in `note_manuell`,
  `qualitaet` = „Sicht-Bonitur“.
- Testversion: Unter `/vorschau/` (Workflow „Seite veröffentlichen“ mit
  Zweigname) läuft eine Testversion mit eigener Datenbank und eigenem
  Offline-Speicher; echte Daten bleiben unberührt.
- Repository-Aufbau (Vorschlag, genau festgelegt in B1 und `CLAUDE.md`):
  `kern/`, `werkstatt/`, `app/`, `bibliotheken/`, `tests/`, `referenzbilder/`,
  `docs/` (Spezifikation, `FORTSCHRITT.md`, Pilotbericht), `.github/workflows/`.
- Tests: Zu jedem Referenzbild ein gespeicherter Sollwert; GitHub Actions
  rechnet bei jedem Pull Request alle Referenzbilder neu.

### Bausteine

| Nr. | Inhalt | Etappe |
|---|---|---|
| B1 | Analyse-Kern + automatische Tests mit Referenzbildern, `CLAUDE.md`, `docs/FORTSCHRITT.md` | 4 |
| B2 | Analyse-Werkstatt | 4 |
| B3 | App-Grundgerüst, Hosting, offline (PWA) | 5 |
| B4 | Sitzungen & Stammdaten (Sätze, Sorten, Behandlungen, Kürzel) | 5 |
| B5 | Aufnahme/Import + Foto-Archiv | 5 |
| B6 | Analyse in der App, Kontrollbild, Qualitätschecks | 5 |
| B7 | QR-Etiketten drucken + QR aus dem Foto lesen | 5 |
| B8 | Export (Excel + ZIP) + Sicherungs-Erinnerung | 5 |
| B9 | Einstellungen/Kalibrierung, Übersicht, Verlauf, AUDPC | 5 |

---

## Kalibrieren

- 100–200 neue Töpfe (nicht die Pilot-Töpfe), zwei Personen, `note_manuell`.
- Schwellen und Umrechnungstabelle an der Übungshälfte einstellen, an der
  Prüfhälfte prüfen. Freigabe mit denselben Kriterien wie GO.
- Neu prüfen bei neuer Sorte, neuer Saison, neuem Handy, neuen LEDs, neuer
  Farbkarte, geändertem Algorithmus; zusätzlich vierteljährlich 20 Töpfe doppelt.
- Kontroll-Pflanze (Kunstpflanze) wöchentlich fotografieren; Werte müssen im
  Toleranzband bleiben.

---

## Betrieb

- Kurzanleitung an der Box (Leitfaden 11.2).
- Nach jeder Sitzung Excel + Foto-ZIP nach `Bonitur/JJJJ/JJJJ-MM-TT_SatzNN/`
  sichern. Browser-Speicher ist kein Archiv.
- Auswertung: Mittelwerte je Satz/Behandlung/Termin, Verlauf, AUDPC = Summe über
  aufeinanderfolgende Termine von (Befall₁ + Befall₂) / 2 × Tage dazwischen.
- Datenschutz: nur Kürzel.

---

## Quellen

- Ben Naim et al. 2025, *Planta*: https://pmc.ncbi.nlm.nih.gov/articles/PMC12122581/
- UMN Extension: https://extension.umn.edu/diseases/basil-downy-mildew
- Cornell: https://www.vegetables.cornell.edu/pest-management/disease-factsheets/basil-downy-mildew/
- LeafScan (MIT): https://github.com/LeonLenzo/leaf-scan
- PlantCV Farbkorrektur: https://docs.plantcv.org/en/latest/transform_correct_color/
- Open Camera: https://opencamera.org.uk/
- X-Rite/Calibrite Sollwerte ab 2014: https://www.xrite.com/en/service-support/new_color_specifications_for_colorchecker_sg_and_classic_charts

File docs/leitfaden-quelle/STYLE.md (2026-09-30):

# HTML-KONVENTIONEN für Kapitel-Fragmente (wird zu PDF, A4, via Chromium)

Liefere NUR ein HTML-Fragment (kein <html>, <head>, <body>, kein <style>, kein <script>).
Jedes Kapitel ist genau ein Element:

<section class="chapter" id="kap-N">            (Anhänge: id="anh-a", id="anh-b")
  <p class="kicker">Etappe 1 · ca. 1–3 Wochen</p>   (Erklärkapitel: z. B. "Hintergrund"; Anhang: "Anhang")
  <h1>4 Die Fotobox bauen</h1>                 (Nummer + Titel; Anhang: "A Glossar")
  <p class="lead">Ein bis zwei Sätze: worum es geht und was am Ende steht.</p>
  ...
</section>

Erlaubte Bausteine (nur diese Klassen verwenden):
- <h2>4.1 Titel</h2>, <h3>Untertitel</h3> (h3 ohne Nummer), <p>, <ul>, <ol>, <strong>, <em>, <code>.
- Etappen-Steckbrief direkt nach dem lead (nur Etappen-Kapitel):
  <table class="stage-meta">
    <tr><th>Ziel</th><td>…</td></tr>
    <tr><th>Dauer</th><td>…</td></tr>
    <tr><th>Du</th><td>…</td></tr>
    <tr><th>Claude</th><td>…</td></tr>
    <tr><th>Du brauchst</th><td>…</td></tr>
    <tr><th>Ergebnis</th><td>…</td></tr>
  </table>
- Hinweisboxen: <div class="box tip"><p class="box-title">Tipp</p><p>…</p></div>
  Varianten: tip (Tipp), warn (Achtung), info (Hintergrund/Wissen), decision (Entscheidung).
- Schritt-für-Schritt: <ol class="steps"><li><strong>Kurzer Schritt-Titel.</strong> Erklärung …</li></ol>
- Checkliste zum Abhaken: <ul class="checklist"><li>…</li></ul>  (Kästchen kommen per CSS)
- Tabelle: <table class="t"><thead><tr><th>…</th></tr></thead><tbody><tr><td>…</td></tr></tbody></table>
  Tabellen-Überschrift optional davor: <p class="table-caption">Tabelle 4.1: …</p>
- Rollen-Marker im Fließtext: <span class="who du">Du</span> · <span class="who claude">Claude</span> ·
  <span class="who team">Team</span>
- Kopier-Prompt für Claude:
  <div class="prompt"><p class="prompt-title">Prompt für Claude – B1 Analyse-Kern</p><pre>… Text …</pre></div>
  (In <pre> Zeilen max. ca. 85 Zeichen, sonst läuft Text aus der Box – bitte manuell umbrechen.
   HTML-Sonderzeichen escapen: &lt; &gt; &amp;)
- Kopiervorlage (ganze Seite zum Ausdrucken): <div class="template"> … </div> (darin h3, table.t usw.)
  Davor ggf.  wenn die Vorlage auf eigener Seite beginnen soll.
- Abbildung mit Inline-SVG:
  <figure><svg viewBox="0 0 800 400" role="img" aria-label="…"> … </svg>
  <figcaption>Abb. 4.1: …</figcaption></figure>

SVG-Regeln:
- viewBox setzen, KEINE width/height-Attribute am <svg> (Breite kommt per CSS = 100 %).
- Nur inline, keine externen Bilder/Fonts/Skripte. font-family="Source Sans 3, sans-serif" an Texten
  oder am <svg>; Schriftgröße in viewBox-Einheiten 13–18 (bei viewBox-Breite 800), damit gedruckt lesbar.
- Farben (nur diese): Tinte #1F2A24 · Grau #6B7570 · Linie #C9D2C6 · Hintergrund hell #F3F6F1 ·
  Dunkelgrün #2F6B3A · Blattgrün #5B9A3C · Gelb #D9B32E · Braun #8A5A2B · Rot-Markierung #C0392B ·
  Blau (Technik/Claude) #2B5D8C · Weiß #FFFFFF.
- Einfach und klar: beschriftete Kästen, Pfeile (marker in <defs>, IDs mit Kapitelpräfix, z. B.
  id="k4-arrow", damit IDs im Gesamtdokument eindeutig sind), Maßlinien. Nichts Überladenes.
  Texte dürfen nicht über Kästen hinauslaufen: Kästen groß genug, Text ggf. auf 2 <tspan>-Zeilen.
- Maximal ca. 2–4 Abbildungen pro Kapitel, nur wo sie wirklich helfen.

Nummerierung: Abschnitte "4.1", Abbildungen "Abb. 4.1", Tabellen "Tabelle 4.1" – immer mit der
Kapitelnummer. Querverweise als Text („siehe Kapitel 7.3"), keine Links nötig; externe Links als
<a href="…">sichtbarer Text</a>.

Ton: Du-Form, freundlich, konkret, kurze Sätze, keine Füllwörter, kein Marketing. Fachbegriffe beim
ersten Auftreten kurz erklären (Glossar in Anhang A). Keine Emojis. Deutsche Anführungszeichen „…".
Zahlen: Dezimalkomma (0,6), Einheiten mit Leerzeichen (50 cm, 5 V). Schätzungen als solche kennzeichnen.
Nichts erfinden: Keine erfundenen Menüpfade, Preise oder Quellen. Wenn unsicher: allgemein formulieren
oder als „prüfen" kennzeichnen.

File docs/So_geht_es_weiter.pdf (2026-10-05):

## EINFACH ERKLÄRT

# Mehltau-Bonitur:

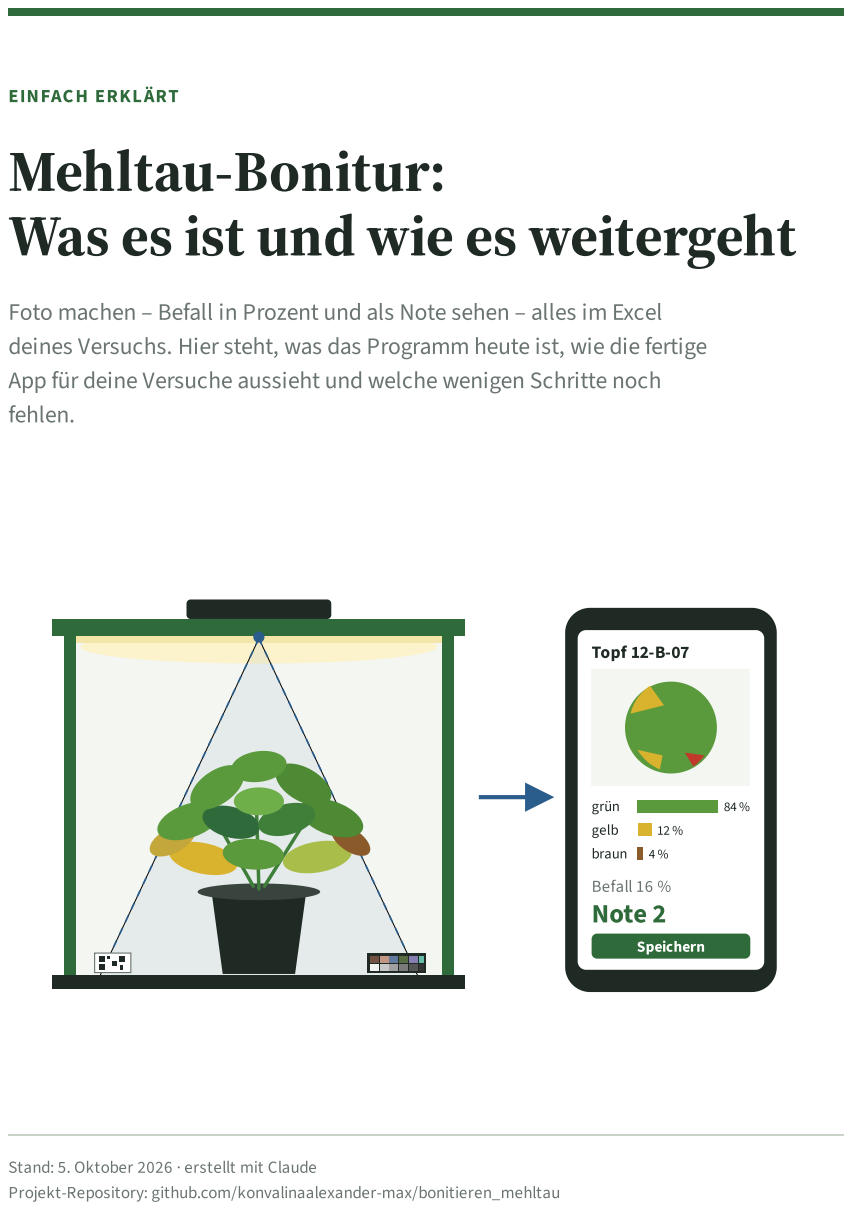
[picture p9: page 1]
fehlen.; Topf 12-B-07; grün; gelb; braun; Befall 16 % Note 2; Speichern

Was es ist und wie es weitergeht

Foto machen – Befall in Prozent und als Note sehen – alles im Excel

deines Versuchs. Hier steht, was das Programm heute ist, wie die fertige

App für deine Versuche aussieht und welche wenigen Schritte noch

Stand: 5. Oktober 2026 · erstellt mit Claude

Projekt-Repository: github.com/konvalinaalexander-max/bonitieren_mehltau

Mehltau-Bonitur · Was es ist und wie es weitergeht · 5. Oktober 2026 | Seite 2

ÜBERSICHT

# Inhalt

1 Das Wichtigste auf einer Seite | 3
1.1 Was es heute schon gibt | 3
1.2 Was ich jetzt vereinfache | 3
1.3 Wie es weitergeht | 3
2 So sieht die fertige App aus | 4
2.1 Einen Versuch anlegen – einmal je Versuch | 4
2.2 Fotografieren – an jedem Boniturtermin | 4
2.3 Das Excel | 5
2.4 Schnell messen – ohne Versuch | 6
2.5 Was du nicht brauchst | 6
2.6 Wie genau ist das? | 6
3 Was das Programm heute ist | 7
3.1 Die Teile auf einen Blick | 7
3.2 So rechnet die App | 7
3.3 Was schon geprüft ist – und was nicht | 8
4 Was ich an der App vereinfache | 9
5 Der Weg bis zum ersten Versuch | 10
5.1 Schritt 1: Kurz entscheiden | 10
5.2 Schritt 2: Fotobox – kaufen statt bauen | 10
5.3 Schritt 3: Handy und App einrichten | 11
5.4 Schritt 4: Probelauf | 11
5.5 Schritt 5: Erster echter Versuch | 11
5.6 Wer macht was | 11
6 Was ich jetzt von dir brauche | 12
A GitHub einschalten – einmalig | 14
Kleines Wörterbuch | 14

Mehltau-Bonitur · Was es ist und wie es weitergeht · 5. Oktober 2026 | Seite 3

ZUSAMMENFASSUNG

# 1 Das Wichtigste auf einer Seite

Bei Versuchen nicht mehr von Hand auszählen: Foto machen, die App sagt sofort, wie stark der

Befall ist – und am Ende steht alles sauber in einem Excel, das du als Versuchsdaten nutzt.

Topf wählen → Foto → „Befall 12 % · Note 2“ → nächster Topf.

Am Ende: ein Excel mit allenWerten deinesVersuchs.

## 1 Versuch planen

Name, Varianten,

Töpfe je Variante

einmal· ca. 2 Minuten

## 2 Fotografieren

Topf wählen → Foto →

Befall % und Note

je Topf ca. 20–30 Sekunden

## 3 Excel holen

alleWerte, Mittelwerte

je Variante und Termin

ein Tipp

Abb. 1.1: Dein Ablauf bei jedem Versuch. Schritt 2 wiederholst du an jedem Termin – alles landetim selben Excel.

## 1.1 Was es heute schon gibt

Alles im Hintergrund ist fertig programmiert und mit künstlichen Fotos getestet: Auswertung der Fotos, Handy-

App, PC-Seite zum Einrichten („Werkstatt“), Druckseite für Topf-Karten, Pläne für die Fotobox. Läuft im Browser,

ohne Installation und ohne Internet (Kapitel 3).

## 1.2 Was ich jetzt vereinfache

Die App kann heute mehr, als du brauchst. Ich schneide sie auf deinen Ablauf zu: Versuch anlegen,

fotografieren, Excel holen – kein Dashboard, keine Listen. Die Rechnung bleibt gleich (Kapitel 2 und 4).

## 1.3 Wie es weitergeht

Fünf Schritte, geschätzt 3–5 Wochen je nach Lieferzeiten (Kapitel 5): 1 kurz entscheiden (15 Minuten) · 2 Fotobox

besorgen – am einfachsten ein Lichtzelt kaufen · 3 Handy und App einrichten (1–2 Stunden) · 4 Probelauf mit 50

Töpfen · 5 erster echter Versuch.

WAS ICH JETZT VON DIR BRAUCHE

Dein OK zum Vereinfachen der App und 7 kurze Antworten (Kapitel 6). Du kannst einfach hier im Chat

antworten. Das 15-Fragen-PDF vom Vormittag musst du nicht mehr durcharbeiten.

Mehltau-Bonitur · Was es ist und wie es weitergeht · 5. Oktober 2026 | Seite 4

ZIEL

# 2 So sieht die fertige App aus

So arbeitest du später bei jedem Versuch. Die Bilder sind Skizzen des Plans – gebaut wird nach

deinem OK.

Mehltau-Bonitur

Deine Versuche

Fungizid-TestOkt

3 Varianten · 30 Töpfe

heute: 12 von 30

Sortenvergleich

2 Varianten · 20 Töpfe

+ Neuer Versuch

Schnell messen

ohne Versuch: Foto → Ergebnis

1 · Start

‹Neuer Versuch

Name

Fungizid-Test Okt

Varianten

A | unbehandelt
B | Mittel X
C | Mittel Y

+ Variante

Töpfe je Variante

10 | → A1–A10, B1–B10 …

Versuch anlegen

2 · Versuch anlegen

‹ Fungizid-TestOkt

Waswird fotografiert?

nächster Topf
A4

Variante A · unbehandelt

anderer Topf? antippen

A1 ✓ | A2 ✓ | A3 ✓ | A4 | A5
B1 | B2 | B3 | B4 | B5
C1 | C2 | C3 | C4 | C5

…

Foto machen

3 · Topfwählen

Abb. 2.1: Start, Versuch anlegen, Topf wählen (Skizze)

## 2.1 Einen Versuch anlegen – einmal je Versuch

Name, z. B. „Fungizid-Test Okt“.

Varianten, z. B. A = unbehandelt, B = Mittel X, C = Mittel Y. Eine unbehandelte Kontrolle gehört immer dazu.

Töpfe je Variante, z. B. 10. Die App nummeriert die Töpfe selbst: A1 bis A10, B1 bis B10 …

Wahlweise Sorte und eine Notiz. Topf-Karten mit QR-Code für genau diese Töpfe druckst du auf Wunsch mit

einem Klick.

## 2.2 Fotografieren – an jedem Boniturtermin

Was wird fotografiert? Die App schlägt den nächsten Topf vor (A1, A2 …). Ist es ein anderer, tippst du ihn

an. Liegt eine Topf-Karte mit QR-Code in der Box, prüft die App zusätzlich selbst, ob es der richtige Topf ist.

1

2 | Foto. Topf in die Box, Klappe zu, großer Knopf.
| Ergebnis. Groß: „12 %“ und „Note 2“. Klein darunter das Kontrollbild, auf dem du siehst, was gezählt
| wurde.

3

4 Weiter. Ein Tipp – schon ist der nächste Topf dran. War ein Blatt eingeklemmt: „Nochmal“.

12 %

## Heute fertig ✓

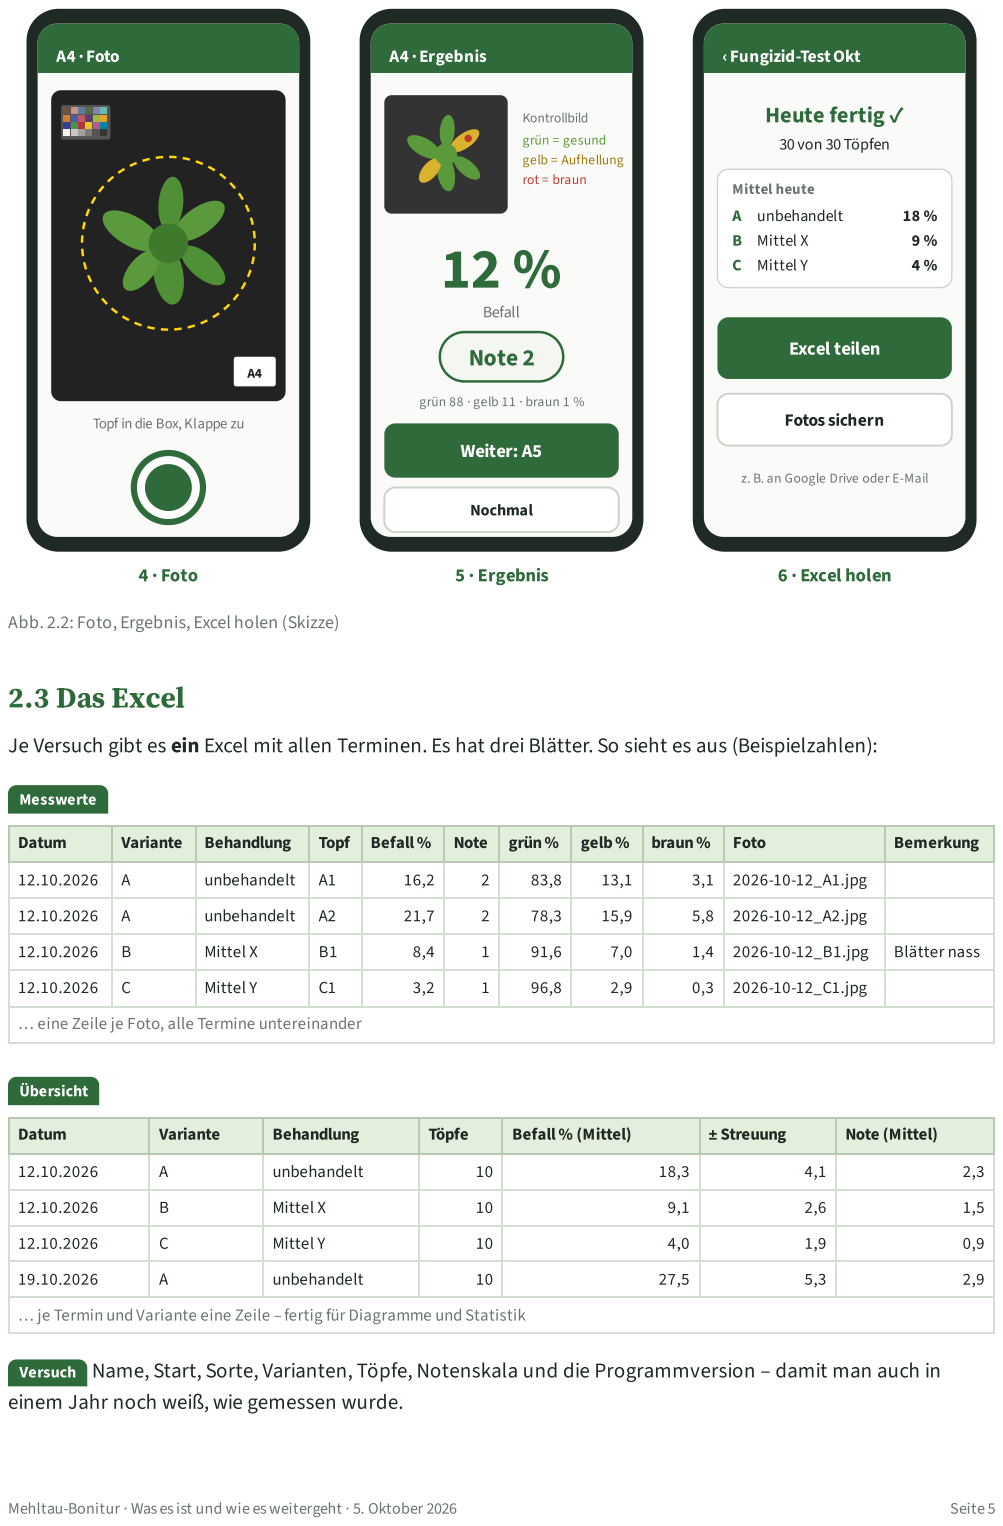
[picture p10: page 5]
Mehltau-Bonitur · Was es ist und wie es weitergeht · 5. Oktober 2026; Seite 5; A4 · Foto; 4 · Foto; A4 ·Ergebnis; Kontrollbild; grün = gesund; gelb = Aufhellung; rot = braun; Befall; Note 2; Weiter: A5; Nochmal; 5 · Ergebnis; ‹ Fungizid-TestOkt; 30 von 30 Töpfen; Mittel heute; unbehandelt; Mittel X; Mittel Y; Excel teilen; Fotos sichern; 6 · Excel holen; 2.3 Das Excel; Messwerte; Übersicht

grün 88 · gelb 11 · braun 1 %

Topf in die Box, Klappe zu

z. B. an Google Drive oder E-Mail

Abb. 2.2: Foto, Ergebnis, Excel holen (Skizze)

Je Versuch gibt es ein Excel mit allen Terminen. Es hat drei Blätter. So sieht es aus (Beispielzahlen):

Datum | Variante | Behandlung | Topf | Befall % | Note | grün% | gelb% | braun% | Foto | Bemerkung

12.10.2026 | A | unbehandelt | A1 | 16,2 | 2 | 83,8 | 13,1 | 3,1 | 2026-10-12_A1.jpg

12.10.2026 | A | unbehandelt | A2 | 21,7 | 2 | 78,3 | 15,9 | 5,8 | 2026-10-12_A2.jpg

12.10.2026 | B | Mittel X | B1 | 8,4 | 1 | 91,6 | 7,0 | 1,4 | 2026-10-12_B1.jpg | Blätter nass

12.10.2026 | C | Mittel Y | C1 | 3,2 | 1 | 96,8 | 2,9 | 0,3 | 2026-10-12_C1.jpg

… eine Zeile je Foto, alle Termine untereinander

Datum | Variante | Behandlung | Töpfe | Befall % (Mittel) | ± Streuung | Note (Mittel)

12.10.2026 | A | unbehandelt | 10 | 18,3 | 4,1 | 2,3

12.10.2026 | B | Mittel X | 10 | 9,1 | 2,6 | 1,5

12.10.2026 | C | Mittel Y | 10 | 4,0 | 1,9 | 0,9

19.10.2026 | A | unbehandelt | 10 | 27,5 | 5,3 | 2,9

… je Termin und Variante eine Zeile – fertig für Diagramme und Statistik

Versuch Name, Start, Sorte, Varianten, Töpfe, Notenskala und die Programmversion – damit man auch in

einem Jahr noch weiß, wie gemessen wurde.

Mehltau-Bonitur · Was es ist und wie es weitergeht · 5. Oktober 2026 | Seite 6

Die Fotos sicherst du mit einem Tipp als ZIP-Datei. Sie heißen dann sprechend, z. B. 2026-10-12_A4.jpg .

## 2.4 Schnell messen – ohne Versuch

Für zwischendurch: „Schnell messen“, Foto, Ergebnis. Nichts wird gespeichert – außer du willst es.

## 2.5 Was du nicht brauchst

kein Dashboard, keine Diagramme in der App – die Zahlen kommen ins Excel, auswerten tust du dort,

keine Listen pflegen (Sätze, Tische, Sorten) – alles steckt im Versuch,

keine zweite Kamera-App, wenn der Kamera-Test am Box-Handy passt,

im Alltag weder PC noch Werkstatt.

## 2.6 Wie genau ist das?

Der Befall in Prozentist der eigentliche Messwert: der Anteil gelber und brauner Blattfläche an der

ganzen Pflanze, von oben gesehen. Derselbe Topf ergibt bei gleichem Licht fast dieselbe Zahl – gut, um

Varianten zu vergleichen.

Die Note ist eine Umrechnung aus dem Prozent. Die Grenzen stellen wir im Probelauf so ein, dass sie zu

euren Augen passen.

Grenzen: Die App sieht nur Farbe und nur von oben. Sporenrasen auf der Blattunterseite sieht sie nicht;

Gelb aus anderen Gründen (Nährstoffmangel, Alter) zählt sie mit. Deshalb: immer mit einer unbehandelten

Kontrolle vergleichen. Die App misst sichtbare Symptome – sie stellt keine Diagnose.

Mehltau-Bonitur · Was es ist und wie es weitergeht · 5. Oktober 2026 | Seite 7

IST-STAND

# 3 Was das Programm heute ist

Hinter der App stehen ein paar Teile. Im Alltag brauchst du davon nur die App – und die Fotobox.

## 3.1 Die Teile auf einen Blick

Teil | Wofür | Im Alltag?
Handy-App | Versuch, Fotos, Ergebnis, Excel. Läuft im Browser, wird wie eine App aufs Handy gelegt, braucht kein Internet.
ja
Fotobox | Gleiches Licht, gleicher Abstand, dunkler Hintergrund für jedes Foto.
| Ohne sie wären die Zahlen nicht vergleichbar.

ja

Farbkarte | Liegt immer mit im Bild. Die App gleicht damit Farbschwankungen
| aus.

ja (liegt in der

Box)

Werkstatt (PC) | Einmal beim Einrichten: Probelauf prüfen, Notengrenzen einstellen.
| Gibt es auch als einzelne Datei per Doppelklick.

nein

Druckseite | Topf-Karten mit großer Nummer und QR-Code, Maßstab-Karte. | ab und zu
3D-Druckteile | Handyhalter, Abdeckscheibe für die Erde, Halter für Farbkarte und
| Topf-Karte (Ordner fotobox/ ).

einmal

GitHub | Hier liegt alles. Von hier kommt die App per Link aufs Handy, und hier
| werden Änderungen automatisch geprüft.

nein

Leitfaden (95 Seiten) | Nachschlagewerk mit allen Details und Hintergründen. | bei Bedarf

## 3.2 So rechnet die App

Mehltau-Bonitur · Was es ist und wie es weitergeht · 5. Oktober 2026 | Seite 8

Abb. 3.1: Links das Foto aus derBox,rechts das Kontrollbild derApp (künstliches Testfoto): grün = gesund, gelb = Aufhellung,rot =

braun. Ergebnis:Befall 36 %,Note 3.

## 3.3 Was schon geprüft ist – und was nicht

Geprüft | Noch nicht geprüft

Die Rechnung stimmt: 65 automatische Tests, bei jeder

Änderung neu.

Künstliche Fotos mit bekanntem Befall: wahr 11,5 % → App

11,9 %; wahr 35,2 % → App 36,1 %.

App und Werkstatt laufen in Chrome, Edge und Safari, auch

offline und als Datei.

Echte Basilikumpflanzen, eure Fotobox, euer Handy.

Ob die Note zu euren Augen passt.

→ Das zeigt der Probelauf (Kapitel 5.4).

UND DIE FRÜHEREN UNTERLAGEN?

Der Leitfaden bleibt ein Nachschlagewerk. Der Weg in diesem PDF ist die vereinfachte Fassung seiner

Etappen 0 bis 6. Das PDF „Stand und Fragen“ ist hiermit ersetzt: Statt 15 Fragen brauche ich nur noch 7

Antworten.

Farben ausgleichen. Die Farbkarte im Bild hat bekannte Farben. Die App rechnet jedes Foto so um, dass

diese Farben stimmen – so ist jedes Foto gleich „geeicht“.

1

2 | Nur die Pflanze. Gezählt wird im Topfkreis. Die schwarze Abdeckscheibe verdeckt Erde und Topfrand.
3 | Jeden Bildpunkt einordnen: grün, gelb oder braun – nach seinem Farbton.
| Befall % = gelb + braun im Verhältnis zur ganzen Pflanzenfläche. Daraus wird über die Notentabelle die Note (Vorschlag: 0 unter 2 % · 1 bis 10 % · 2 bis 25 % · 3 bis 50 % · 4 über 50 %).
4

Mehltau-Bonitur · Was es ist und wie es weitergeht · 5. Oktober 2026 | Seite 9

UMBAU

# 4 Was ich an der App vereinfache

Die Rechnung bleibt, die Bedienung wird einfach. Nach deinem OK baue ich das in ein bis zwei

Arbeitssitzungen um und teste es wieder automatisch.

Heute | Künftig
Start mit Sitzungen; Sätze, Sorten, Behandlungen, Tische als Listen | Start mit deinen Versuchen und einem großen Knopf
Topf-Nummer eintippen oder aus dem QR-Code | „Was wird fotografiert?“ – der nächste Topf ist vorgeschlagen, der QR-Code prüft mit
Ergebnisseite mit vielen Zahlen und Feldern | Groß Befall % und Note, dann „Weiter“; Details nur bei Bedarf
Ein Excel je Sitzung | Ein Excel je Versuch über alle Termine, mit Übersicht je Variante und Termin
Fotos heißen BOX_20261012_101532.jpg | Fotos heißen 2026-10-12_A4.jpg
Übersicht, Verlauf, AUDPC und Regelkarte in der App | Mittelwerte im Excel; die Qualitätskontrolle bleibt versteckt in den Einstellungen
Pilot: Noten auf Papier und in einer eigenen Excel | Probelauf-Modus: Noten direkt in der App eintippen, die App
| zeigt ihr Ergebnis erst danach
Einrichten mit vielen Reglern | Einmal am Handy: Farbkarte und Topfkreis antippen – danach
| Ruhe

Was bleibt: der Rechenweg, die Farbkarte, Excel und ZIP, „läuft ohne Internet“ und die Sicherheitsabfrage,

bevor etwas gelöscht wird. Die Werkstatt bleibt für den Probelauf.

Mehltau-Bonitur · Was es ist und wie es weitergeht · 5. Oktober 2026 | Seite 10

FAHRPLAN

# 5 Der Weg bis zum ersten Versuch

Fünf Schritte. Die meisten sind kurz.

1

Entscheiden

15 Minuten

7 Antworten

2

Fotobox

bestellen,

1–2 h aufbauen

3

Handy+ App

1–2 Stunden

einrichten

4

Probelauf

50 Töpfe,

1–2Wochen nebenbei

5

Erster Versuch

loslegen

Parallel zu Schritt 2: Ich vereinfache die App(Kapitel 4).

Abb. 5.1: Der Fahrplan (Zeiten sind Schätzungen)

## 5.1 Schritt 1: Kurz entscheiden

7 Antworten in Kapitel 6. Wo du nichts schreibst, nehme ich meinen Vorschlag.

## 5.2 Schritt 2: Fotobox – kaufen statt bauen

Die Box sorgt dafür, dass jedes Foto unter gleichen Bedingungen entsteht – nur dann sind die Prozentwerte

zwischen Varianten und Terminen vergleichbar. Der einfachste Weg ist ein fertiges, faltbares Fotostudio-

Lichtzelt mit eingebauten LEDs.

Lichtzelt kaufen Vorschlag

Selbst bauen (Leitfaden

Kapitel 4)

Aufwand | auspacken, aufstellen: ca. 1–2 Stunden | Zuschnitt, Druckteile, Zusammenbau: mehrere Tage
Kosten (grob) | ca. 50–150 € plus Farbkarte (Preise prüfen) | ca. 150–250 € plus Farbkarte
Worauf achten | Würfel ab ca. 70–80 cm (große Pflanzen: 80 cm), Öffnung oben für das Handy, LEDs mit CRI/Ra ≥ 90, Dimmer immer auf voll | alles nach Maß
Druckteile | nur Handyhalter über der Öffnung und Abdeckscheibe –
| oder Brett mit Loch und schwarzer Moosgummi

alle 8 Teile

Dazu brauchst du in beiden Fällen: die Farbkarte (Calibrite ColorChecker Classic Mini), einen matt schwarzen

Boden (z. B. Moosgummi) und eine Markierung, wo der Topf steht (Klebeband-Kreuz oder Zentrierring). Schick

mir Modell und Maße des Lichtzelts – dann passe ich Handyhalter und Abdeckscheibe daran an.

Mehltau-Bonitur · Was es ist und wie es weitergeht · 5. Oktober 2026 | Seite 11

## 5.3 Schritt 3: Handy und App einrichten

## 5.4 Schritt 4: Probelauf

Bevor du dich auf die Zahlen verlässt, prüfen wir einmal, ob die App zu euren Augen passt.

50 Töpfe von gesund bis stark befallen, je Notenstufe ca. 10. Fotografieren mit der App im Probelauf-

Modus.

Noten in der App: Du (und wenn möglich eine zweite Person) tippt vor dem Ergebnis die eigene Note ein.

Die App zeigt ihr Ergebnis erst danach – so beeinflusst sie niemanden.

5 Töpfe je 3-mal fotografieren (herausnehmen, wieder hineinstellen) – so sehen wir, wie stabil die Zahl ist.

Ich werte aus und stelle die Notengrenzen ein. Ergebnis: „passt“ – oder ein klarer Hinweis, was zu

verbessern ist.

Der Probelauf ist kleiner als der Pilot im Leitfaden (100–200 Töpfe). Für den Start reicht das; wenn die

Ergebnisse knapp sind, nehmen wir mehr Töpfe dazu.

## 5.5 Schritt 5: Erster echter Versuch

Versuch anlegen, an jedem Termin fotografieren, Excel holen. Tipps: immer eine unbehandelte Kontrolle

mitführen, Pflanzen trocken fotografieren, Klappe zu.

## 5.6 Wer macht was

Schritt | Du | Claude
1 Entscheiden | 7 Antworten (Kapitel 6) | trägt sie ein
2 Fotobox | Lichtzelt und Farbkarte bestellen, aufstellen | App vereinfachen; Handyhalter ans Zelt anpassen
3 Handy + App | App installieren, Kamera-Test, Farbkarte antippen | hilft bei Fragen, wertet den Kamera-Test aus
4 Probelauf | 50 Töpfe fotografieren und benoten, Excel
| schicken

auswerten, Notengrenzen einstellen

5 Versuch | Versuch anlegen, fotografieren, Excel nutzen | Feinschliff nach deinen Rückmeldungen

Ein festes Android-Handy bleibt immer bei der Box. Ein vorhandenes reicht, wenn die Kamera

mindestens 12 Megapixel hat (Leitfaden 3.2).

1

2 | App aufs Handy: Link öffnen, „App installieren“ (dafür einmal GitHub einschalten, Anhang A).
| Kamera-Testin der App: Sie prüft, ob sie Belichtung und Farbe selbst festhalten kann. Wenn ja,
| fotografierst du direkt in der App.

3

4 Einrichten: ein Foto in der Box, Ecken der Farbkarte antippen, Topfkreis ziehen. Fertig.

Mehltau-Bonitur · Was es ist und wie es weitergeht · 5. Oktober 2026 | Seite 12

DEINE ANTWORTEN

# 6 Was ich jetzt von dir brauche

Nur das hier. Antworte einfach im Chat, z. B. „OK, A1 ja, A3 kaufen, A4 Samsung A54 …“. Wo du

nichts schreibst, nehme ich meinen Vorschlag.

OK Darf ich die App wie in Kapitel 2 und 4 vereinfachen?

A1 Passt der Ablauf: Versuch anlegen → Topf wählen → Foto → Ergebnis → Excel?

A2 Wie heißen die Töpfe, und kommt eine Karte mitin die Box?

A3 Fotobox

A4 Box-Handy (Android)

A5 Notenskala

ja Vorschlag

ja, aber:

ja Vorschlag

anders:

Variante + Nummer (A1, A2 … B1 …) Vorschlag

eigene Bezeichnung:

Topf-Karte mit QR-Code in die Box legen – sicherer gegen Verwechseln Vorschlag

ohne Karte – ich wähle den Topf nur in der App

Lichtzelt kaufen Vorschlag

selbst bauen nach Leitfaden

habe schon etwas:

vorhanden – Hersteller und Modell:

wird gekauft

0–4 wie im Leitfaden (0 keine Symptome … 4 über 50 %) Vorschlag

eigene Skala:

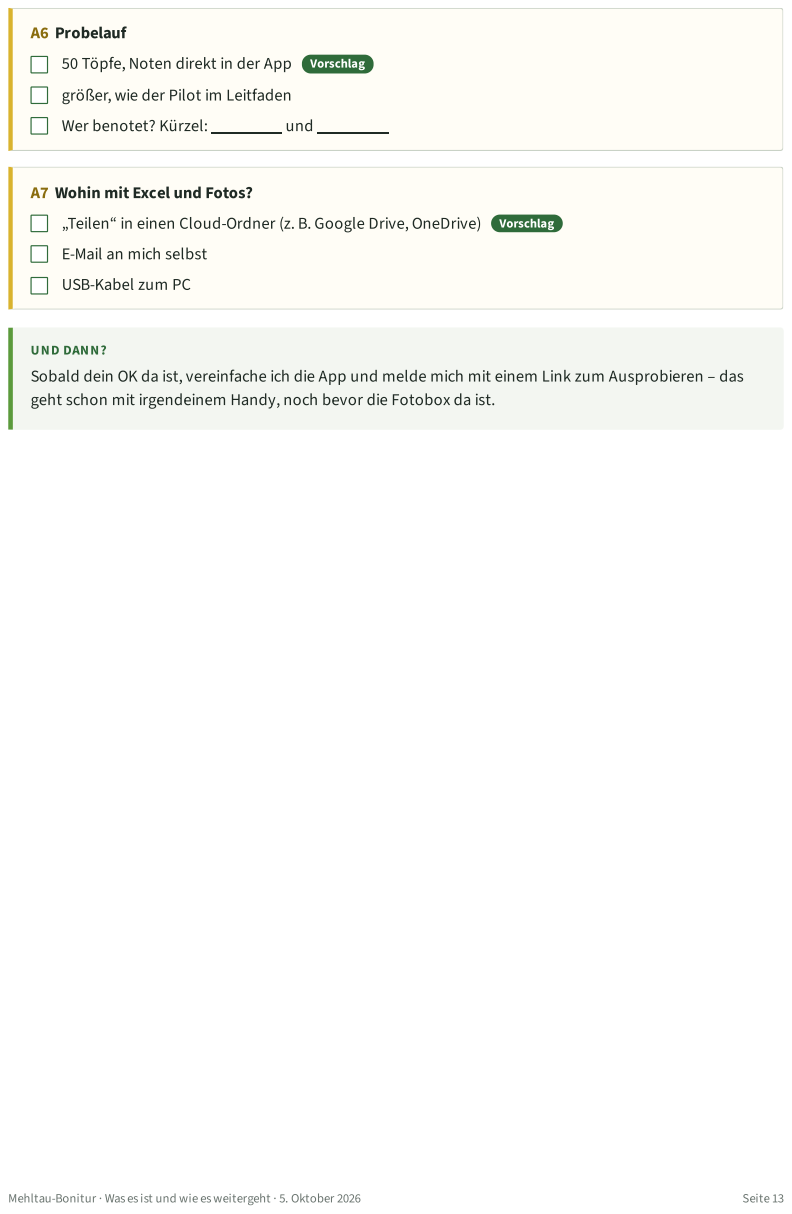
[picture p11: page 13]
Mehltau-Bonitur · Was es ist und wie es weitergeht · 5. Oktober 2026; Seite 13; A6 Probelauf; UND DANN?; 50 Töpfe, Noten direkt in der App; Vorschlag; Wer benotet? Kürzel:; und

größer, wie der Pilot im Leitfaden

A7 Wohin mit Excel und Fotos?

„Teilen“ in einen Cloud-Ordner (z. B. Google Drive, OneDrive) Vorschlag

E-Mail an mich selbst

USB-Kabel zum PC

Sobald dein OK da ist, vereinfache ich die App und melde mich mit einem Link zum Ausprobieren – das

geht schon mit irgendeinem Handy, noch bevor die Fotobox da ist.

# A GitHub einschalten – einmalig

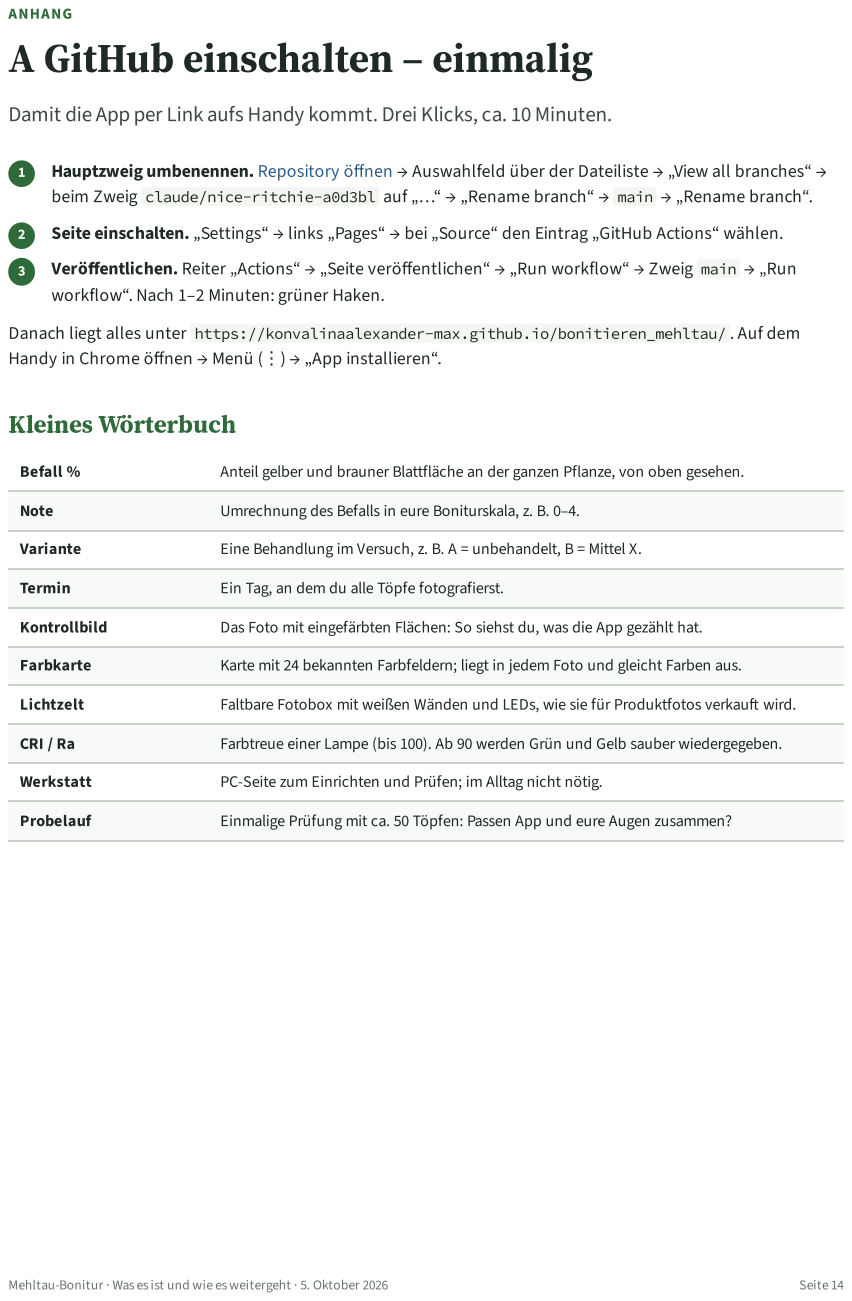
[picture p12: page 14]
Mehltau-Bonitur · Was es ist und wie es weitergeht · 5. Oktober 2026; Seite 14; ANHANG; Kleines Wörterbuch; Befall %; Anteil gelber und brauner Blattfläche an der ganzen Pflanze, von oben gesehen.; Note; Umrechnung des Befalls in eure Boniturskala, z. B. 0–4.; Variante; Eine Behandlung im Versuch, z. B. A = unbehandelt, B = Mittel X.; Termin; Ein Tag, an dem du alle Töpfe fotografierst.; Kontrollbild; Das Foto mit eingefärbten Flächen: So siehst du, was die App gezählt hat.; Farbkarte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

Damit die App per Link aufs Handy kommt. Drei Klicks, ca. 10 Minuten.

beim Zweig claude/nice-ritchie-a0d3bl auf „…“ → „Rename branch“ → main → „Rename branch“.

Hauptzweig umbenennen. Repository öffnen (https://github.com/konvalinaalexander-max/bonitieren_mehltau) → Auswahlfeld über der Dateiliste → „View all branches“ →

Veröffentlichen. Reiter „Actions“ → „Seite veröffentlichen“ → „Run workflow“ → Zweig main → „Run

workflow“. Nach 1–2 Minuten: grüner Haken.

Danach liegt alles unter https://konvalinaalexander-max.github.io/bonitieren_mehltau/ . Auf dem
Handy in Chrome öffnen → Menü (⋮) → „App installieren“.

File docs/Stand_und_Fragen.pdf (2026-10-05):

# Mehltau-Bonitur:

# Stand und Fragen

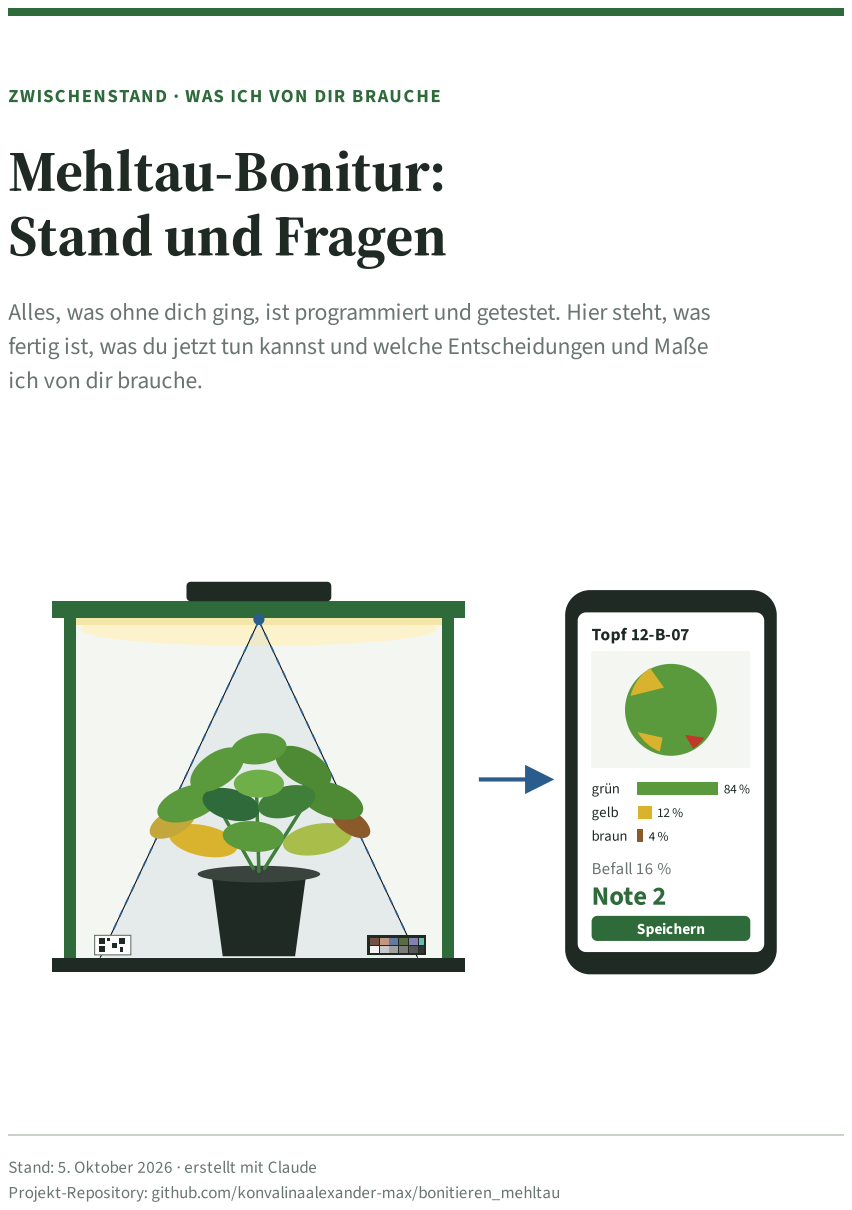
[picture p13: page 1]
Topf 12-B-07; grün; gelb; braun; Befall 16 % Note 2; Speichern

ZWISCHENSTAND · WAS ICH VON DIR BRAUCHE

Alles, was ohne dich ging, ist programmiert und getestet. Hier steht, was

fertig ist, was du jetzt tun kannst und welche Entscheidungen und Maße

ich von dir brauche.

Stand: 5. Oktober 2026 · erstellt mit Claude

Projekt-Repository: github.com/konvalinaalexander-max/bonitieren_mehltau

Mehltau-Bonitur · Stand und Fragen · 5. Oktober 2026 | Seite 2

ÜBERSICHT

# Inhalt

1 Auf einen Blick | 3
1.1 Die nächsten Schritte für dich | 3
2 Was ich gebaut habe | 4
2.1 Übersicht | 4
2.2 Die Handy-App | 4
2.3 Die Analyse-Werkstatt | 5
2.4 Druckseite und Vorlagen | 6
2.5 Die 3D-Druckteile | 7
2.6 So habe ich getestet | 8
3 Das kannst du sofort tun | 9
3.1 Werkstatt-Demo ausprobieren | 9
3.2 GitHub: Hauptzweig und Seite einschalten | 9
3.3 App ansehen (mit irgendeinem Android-Handy) | 10
3.4 Drucken und vorbereiten | 10
4 Meine Fragen an dich | 11
5 Messbögen | 14
5.1 Box-Handy | 14
5.2 Töpfe und Pflanzen | 15
5.3 Material der Fotobox | 16
6 Antworten an Claude schicken | 17
6.1 Wie es danach weitergeht | 17
6.2 Und die Bau-Prompts im Leitfaden? | 18
A Wo finde ich was? | 19

ZUSAMMENFASSUNG

# 1 Auf einen Blick

Analyse, Werkstatt, Handy-App, Druckseite, Vorlagen und die Pläne für die 3D-Druckteile sind

vorab gebaut und mit künstlichen Fotos getestet. Was jetzt fehlt, kann nur von dir kommen:

Entscheidungen, Maße, echte Fotos und ein paar Klicks bei GitHub.

Fotobox

Druckteile geplant

fehlt: deine Maße,

Material, Bau

Box-Handy + App

Appfertig

fehlt: Handy,

Kamera-Test

Export

Excel + ZIP fertig

fehlt: Ablageort,
Übertragungsweg

Werkstatt (PC)

fertig, Demo läuft

fehlt: Pilotfotos

undPilot-Excel

Einstellungsdatei (Farbkarte, Topfkreis, Schwellen, Notentabelle) aus der Werkstatt in die App

Foto | Messwerte | Fotos + Excel

Abb. 1.1: Dievier Teile des Systems und was jeweils noch fehlt(grün = gebaut, gelb = von dir abhängig)

## 1.1 Die nächsten Schritte für dich

WANN BRAUCHE ICH WAS VON DIR?

Jetzt(Etappe 0): Antworten auf die Fragen F1–F15, Maße von Handy, Töpfen und Material.

Etappe 1–2 (Box und Box-Handy): Ein paar Fotos aus der fertigen Box und das Ergebnis der Kamera-

Test-Seite der App.

Etappe 3–4 (Pilot): Pilotfotos und Pilot-Excel auf dem Firmen-PC; die Referenzbilder (ca. 45–55 Fotos)

ins Repository.

Ab Etappe 5: Die Einstellungsdatei aus der Werkstatt am Box-Handy laden, Rückmeldungen aus dem

Alltag.

Werkstatt-Demo ansehen (10 Minuten, geht sofort). So siehst du, wie die Auswertung des Pilots später

aussieht (Kapitel 3.1).

1

GitHub einrichten (10 Minuten). Hauptzweig in main umbenennen und die Seite einschalten – danach

läuft die App auf jedem Handy über eine feste Adresse (Kapitel 3.2).

2

Fragen beantworten (15 Minuten). Ankreuzen in Kapitel 4. Wo du nichts änderst, nehme ich meinen

Vorschlag.

3

4 | Messen (30–60 Minuten). Box-Handy, Töpfe und Material mit Messschieber und Zollstock (Kapitel 5).
| Antworten an Claude schicken. Fertiger Text in Kapitel 6. Dann trage ich alles ein und passe Druckteile,
| App und Vorlagen an.

5

Material bestellen und drucken. Einkaufsliste im Leitfaden 3.8; Topf-Karten, Maßstab-Karte und Bonitur-

Bögen liegen druckfertig bereit (Kapitel 3.4).

6

# 2 Was ich gebaut habe

## 2.1 Übersicht

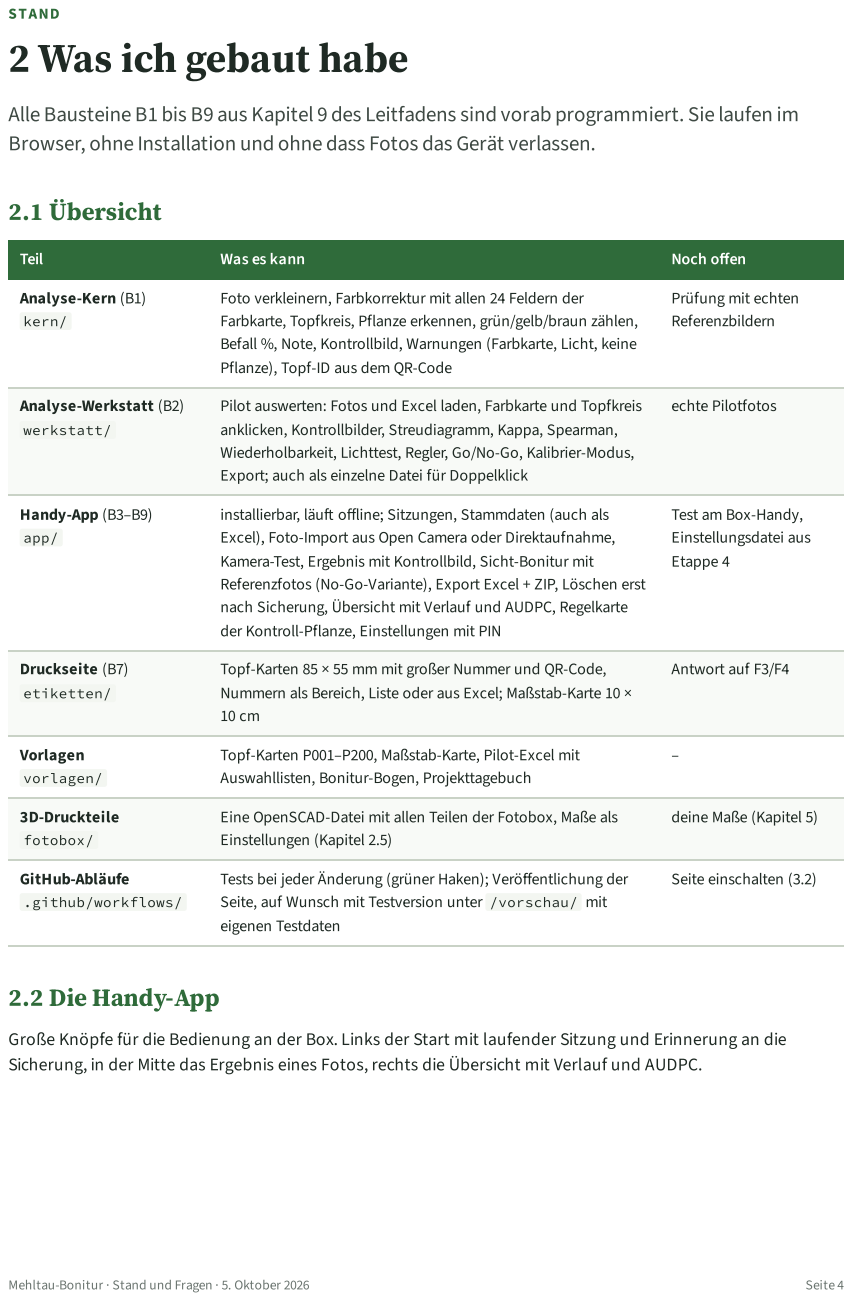
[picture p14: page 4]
STAND; Teil; Was es kann; Noch offen; Analyse-Kern (B1); kern/; Referenzbildern; Analyse-Werkstatt (B2); werkstatt/; echte Pilotfotos; Handy-App (B3–B9); app/; Einstellungsdatei aus; Etappe 4; Druckseite (B7); etiketten/; Antwort auf F3/F4; Vorlagen; vorlagen/; 3D-Druckteile; fotobox/; Einstellungen (Kapitel 2.5); GitHub-Abläufe; .github/workflows/; eigenen Testdaten; Seite einschalten (3.2)

Alle Bausteine B1 bis B9 aus Kapitel 9 des Leitfadens sind vorab programmiert. Sie laufen im

Browser, ohne Installation und ohne dass Fotos das Gerät verlassen.

Foto verkleinern, Farbkorrektur mit allen 24 Feldern der

Prüfung mit echten

Farbkarte, Topfkreis, Pflanze erkennen, grün/gelb/braun zählen,

Befall %, Note, Kontrollbild, Warnungen (Farbkarte, Licht, keine

Pflanze), Topf-ID aus dem QR-Code

Pilot auswerten: Fotos und Excel laden, Farbkarte und Topfkreis

anklicken, Kontrollbilder, Streudiagramm, Kappa, Spearman,

Wiederholbarkeit, Lichttest, Regler, Go/No-Go, Kalibrier-Modus,

Export; auch als einzelne Datei für Doppelklick

installierbar, läuft offline; Sitzungen, Stammdaten (auch als

Test am Box-Handy,

Excel), Foto-Import aus Open Camera oder Direktaufnahme,

Kamera-Test, Ergebnis mit Kontrollbild, Sicht-Bonitur mit

Referenzfotos (No-Go-Variante), Export Excel + ZIP, Löschen erst

nach Sicherung, Übersicht mit Verlauf und AUDPC, Regelkarte

der Kontroll-Pflanze, Einstellungen mit PIN

Topf-Karten 85 × 55 mm mit großer Nummer und QR-Code,

Nummern als Bereich, Liste oder aus Excel; Maßstab-Karte 10 ×

Topf-Karten P001–P200, Maßstab-Karte, Pilot-Excel mit

Auswahllisten, Bonitur-Bogen, Projekttagebuch

Eine OpenSCAD-Datei mit allen Teilen der Fotobox, Maße als

deine Maße (Kapitel 5)

Tests bei jeder Änderung (grüner Haken); Veröffentlichung der

Seite, auf Wunsch mit Testversion unter /vorschau/ mit

2.2 Die Handy-App

Große Knöpfe für die Bedienung an der Box. Links der Start mit laufender Sitzung und Erinnerung an die

Sicherung, in der Mitte das Ergebnis eines Fotos, rechts die Übersicht mit Verlauf und AUDPC.

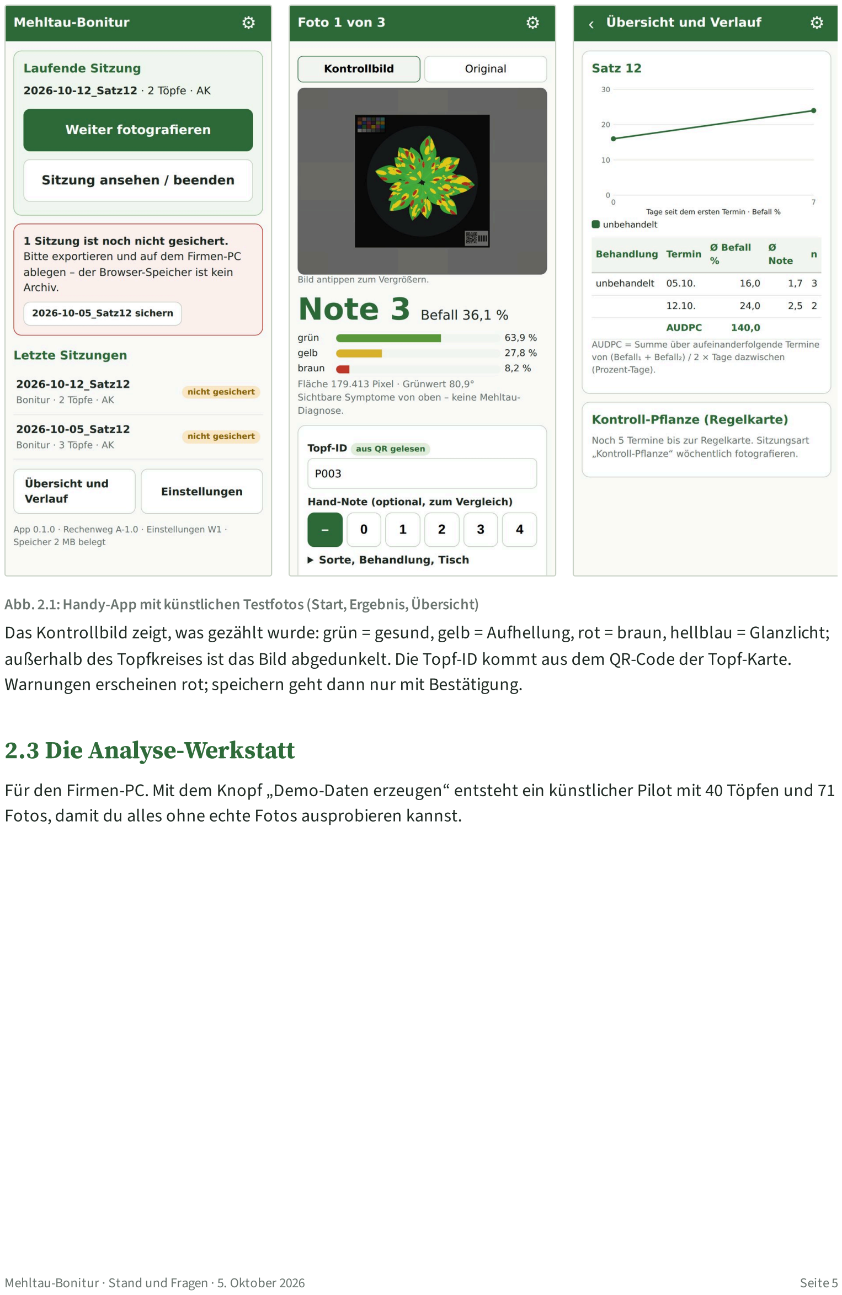
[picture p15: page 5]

Abb. 2.1:Handy-App mit künstlichen Testfotos (Start, Ergebnis,Übersicht)

Das Kontrollbild zeigt, was gezählt wurde: grün = gesund, gelb = Aufhellung, rot = braun, hellblau = Glanzlicht;

außerhalb des Topfkreises ist das Bild abgedunkelt. Die Topf-ID kommt aus dem QR-Code der Topf-Karte.

Warnungen erscheinen rot; speichern geht dann nur mit Bestätigung.

## 2.3 Die Analyse-Werkstatt

Für den Firmen-PC. Mit dem Knopf „Demo-Daten erzeugen“ entsteht ein künstlicher Pilot mit 40 Töpfen und 71

Fotos, damit du alles ohne echte Fotos ausprobieren kannst.

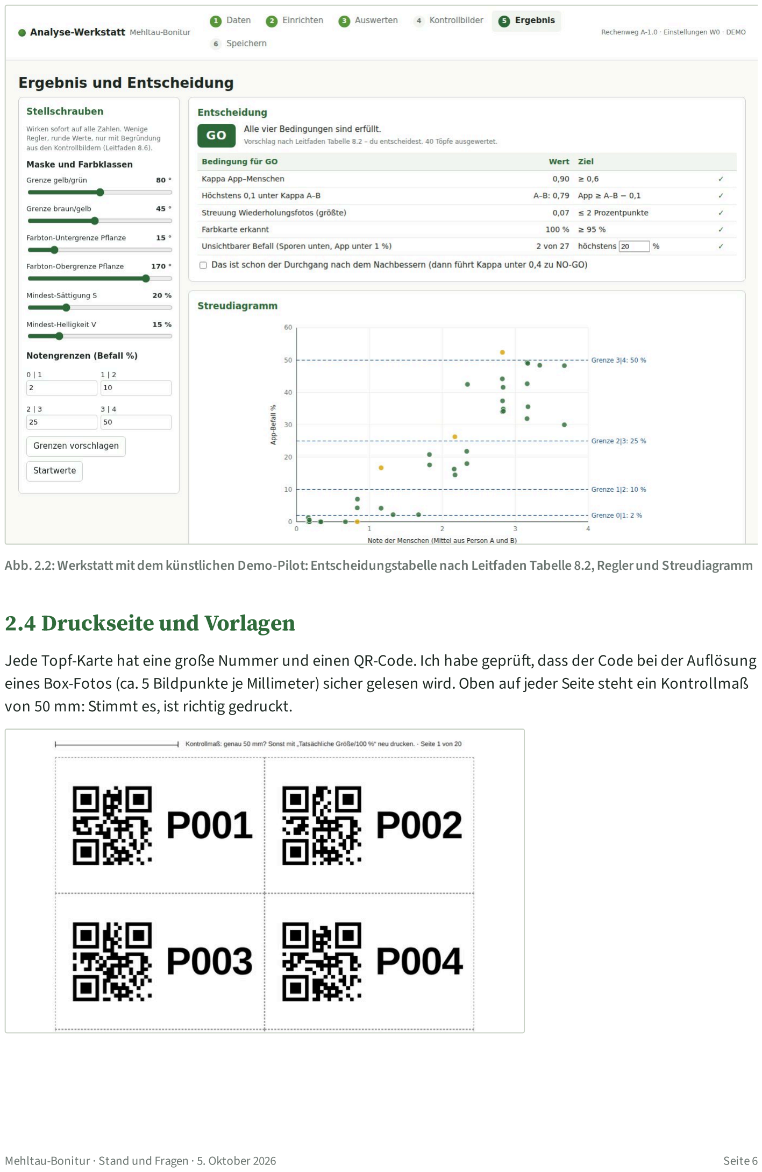
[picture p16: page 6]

Abb. 2.2: Werkstattmitdem künstlichen Demo-Pilot: Entscheidungstabelle nach Leitfaden Tabelle 8.2,Reglerund Streudiagramm
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

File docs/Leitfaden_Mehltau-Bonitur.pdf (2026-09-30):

# Mehltau-Bonitur

# per Handy

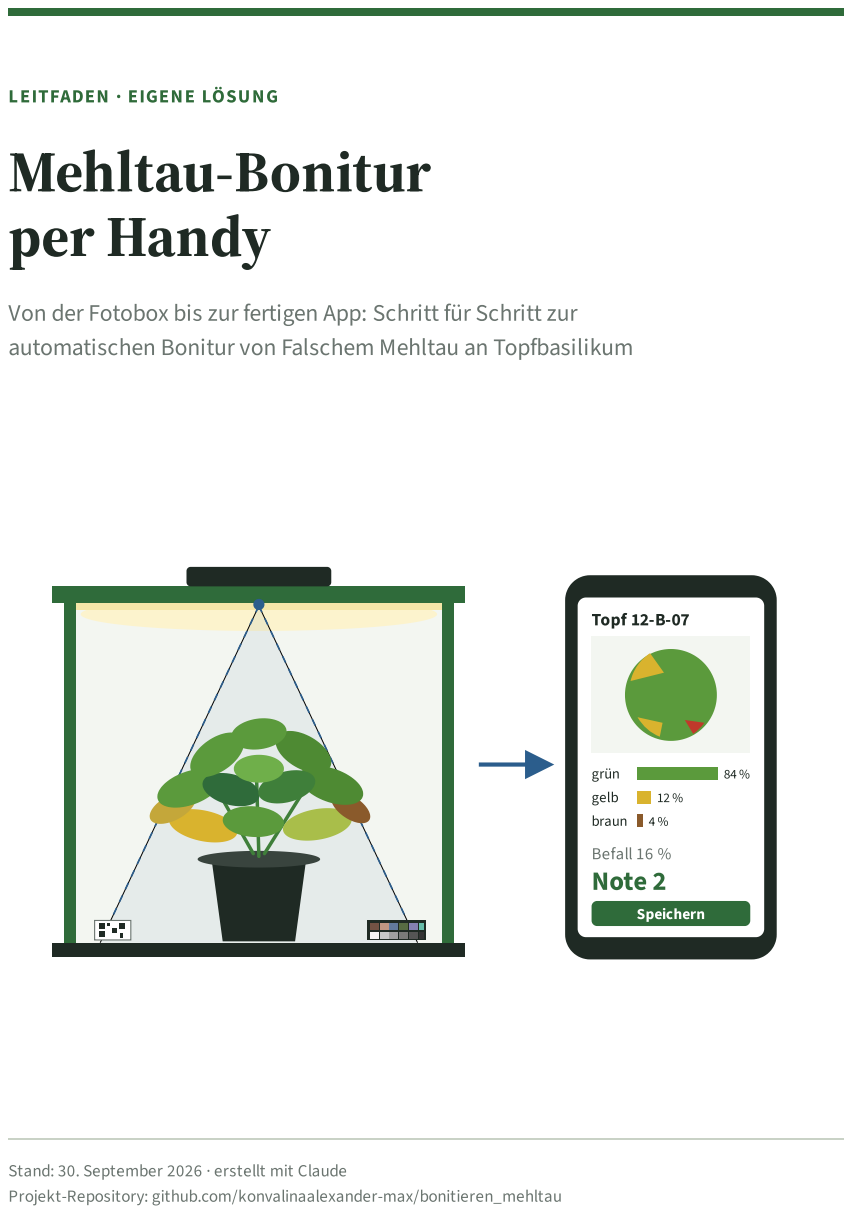
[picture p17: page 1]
Topf 12-B-07; grün; gelb; braun; Befall 16 % Note 2; Speichern

LEITFADEN · EIGENE LÖSUNG

Von der Fotobox bis zur fertigen App: Schritt für Schritt zur

automatischen Bonitur von Falschem Mehltau an Topfbasilikum

Stand: 30. September 2026 · erstellt mit Claude

Projekt-Repository: github.com/konvalinaalexander-max/bonitieren_mehltau

Leitfaden Mehltau-Bonitur | Seite 2

ÜBERSICHT

# Inhalt

1 So benutzt du diesen Leitfaden | 5
1.1 Worum es geht | 5
1.2 Aufbau und Zeichen | 5
1.3 Du musst nicht programmieren können | 5
1.4 So benutzt du die Kopier-Prompts | 6
1.5 Wo die Projektdateien liegen | 6
1.6 Tipp: Führe ein Projekttagebuch | 6
2 Das Gesamtbild | 7
2.1 Was am Ende da ist | 7
2.2 So läuft eine Bonitur später ab | 7
2.3 Der Weg dorthin: acht Etappen | 8
2.4 Erst das Risiko prüfen, dann die App bauen | 8
2.5 Was die App kann – und was nicht | 9
2.6 Kosten und Zeit | 9
3 Vorbereitung und Entscheidungen | 10
3.1 Entscheidung 1: Die Boniturskala | 10
3.2 Entscheidung 2: Das Box-Handy | 11
3.3 Entscheidung 3: Welche Sorten | 11
3.4 Entscheidung 4: Töpfe und Pflanzen ausmessen | 11
3.5 Entscheidung 5: Hosting – öffentliches oder privates Repository | 12
3.6 Entscheidung 6: Wer im Pilot bonitiert | 13
3.7 Entscheidung 7: Wo die Daten gespeichert werden | 14
3.8 Einkaufsliste | 14
3.9 Zugang prüfen: GitHub und Claude Code | 15
3.10 Etappe 0 ist fertig, wenn … | 16
4 Die Fotobox bauen | 17
4.1 Warum eine Box? | 17
4.2 Erst ein Karton-Prototyp | 17
4.3 Maße und Aufbau | 18
4.4 Material und Kosten | 20
4.5 Die 3D-Druckteile | 20
4.6 Zusammenbau | 22
4.7 Licht | 23
4.8 Farbkarte richtig anbringen | 23
4.9 Abdeckscheibe und Etikettenhalter | 24
4.10 Abnahme: Ist die Box fertig? | 24
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

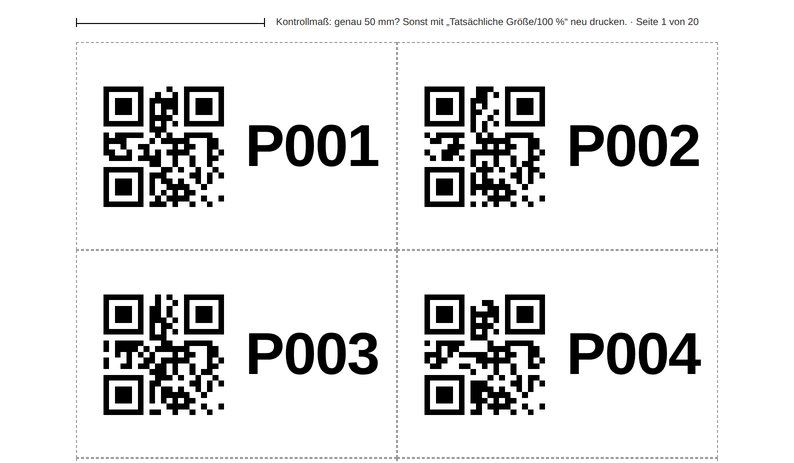
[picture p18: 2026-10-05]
docs/stand-und-fragen/bilder/topfkarten.jpg

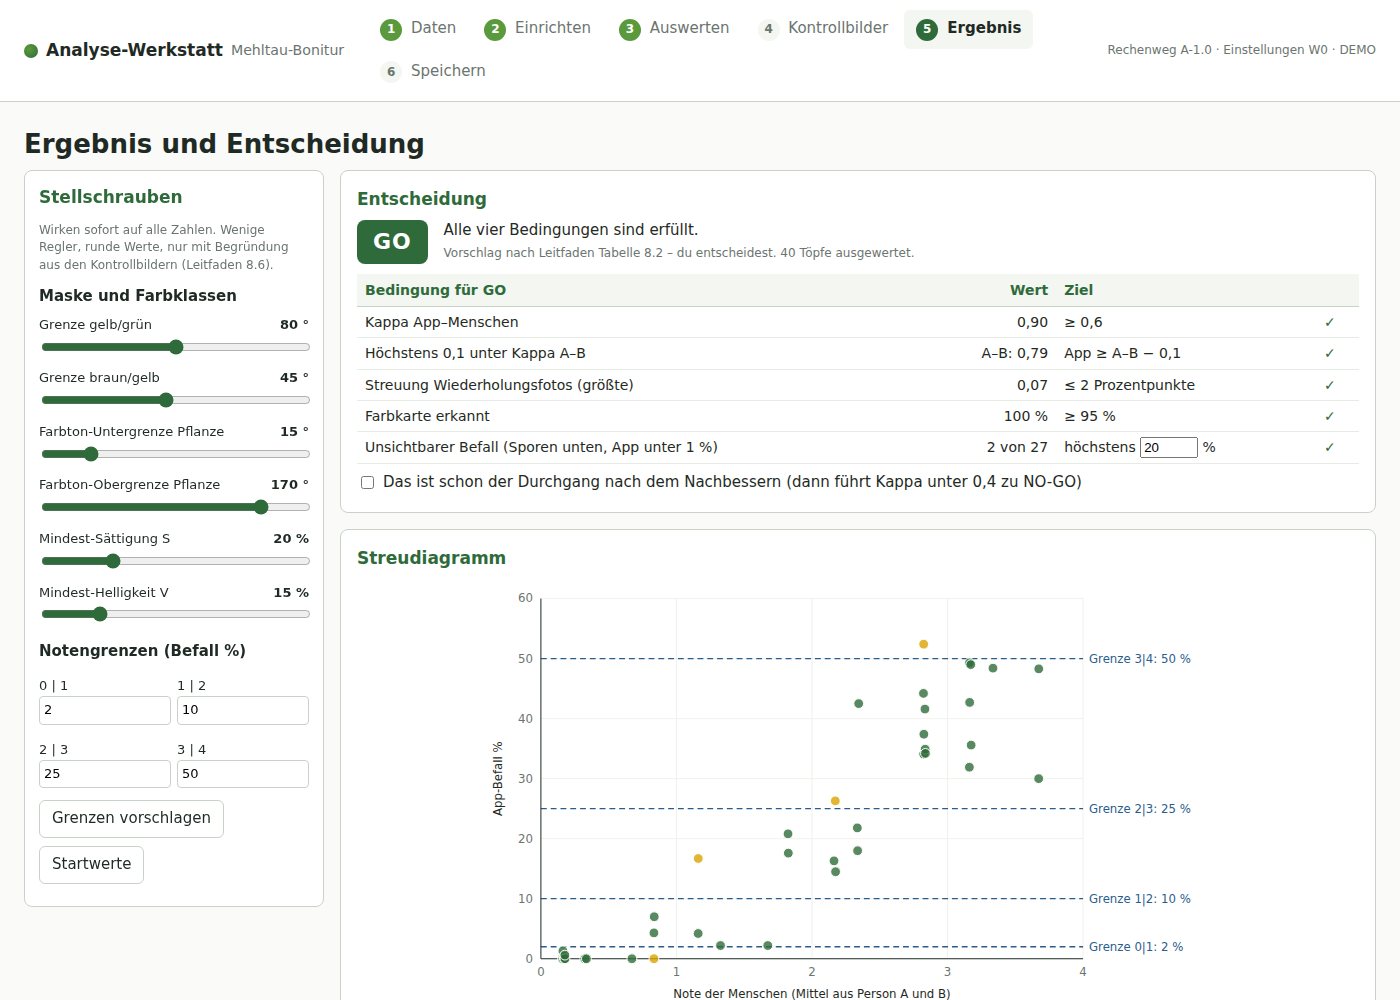
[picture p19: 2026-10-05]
docs/stand-und-fragen/bilder/werkstatt_ergebnis.jpg

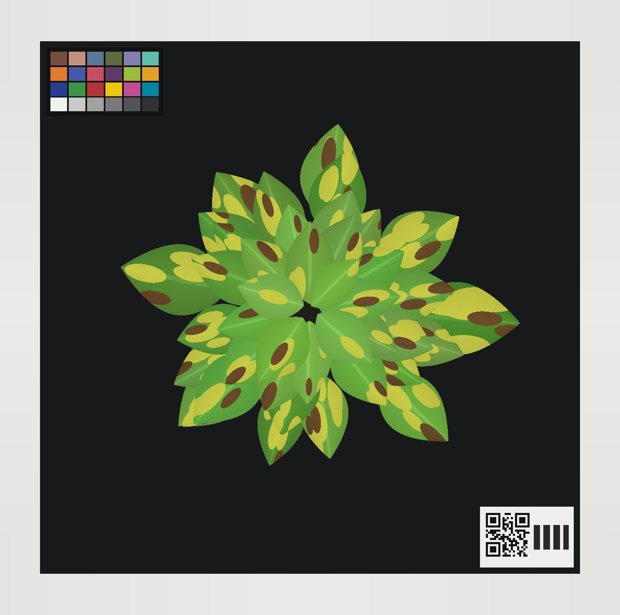
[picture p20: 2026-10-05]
docs/so-geht-es-weiter/bilder/foto.jpg

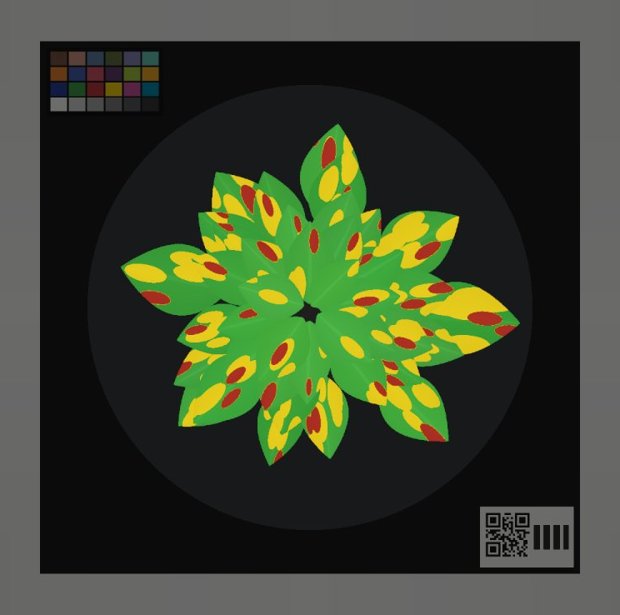
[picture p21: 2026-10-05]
docs/so-geht-es-weiter/bilder/kontrollbild.jpg

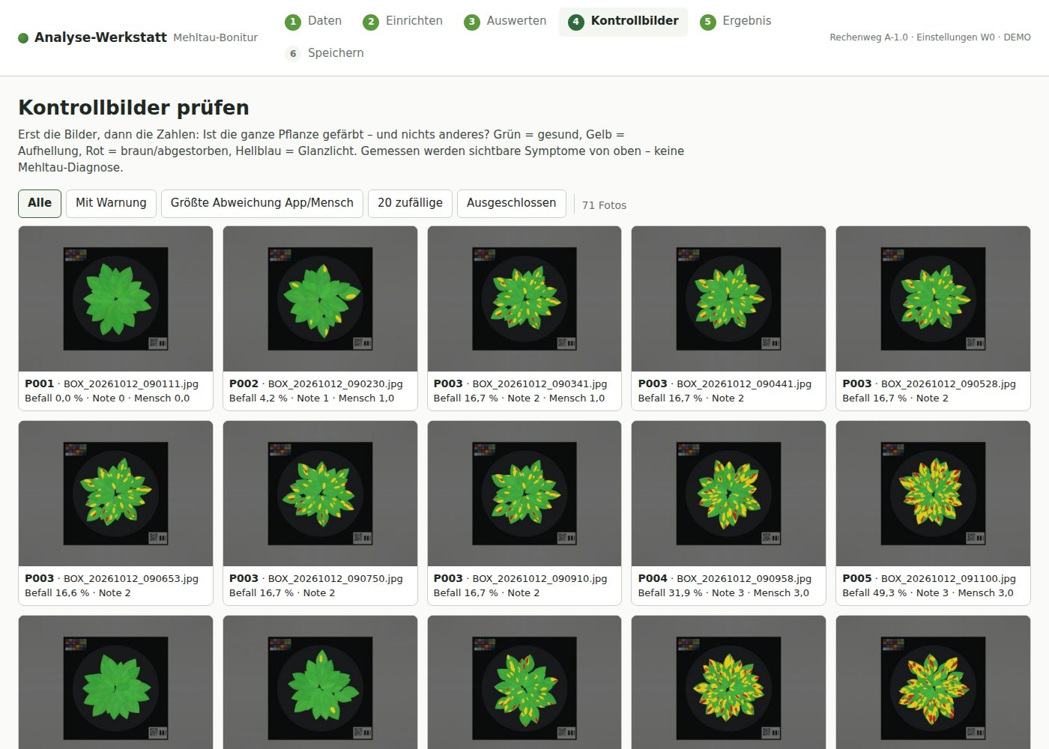
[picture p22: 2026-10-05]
docs/stand-und-fragen/bilder/werkstatt_kontrolle.jpg

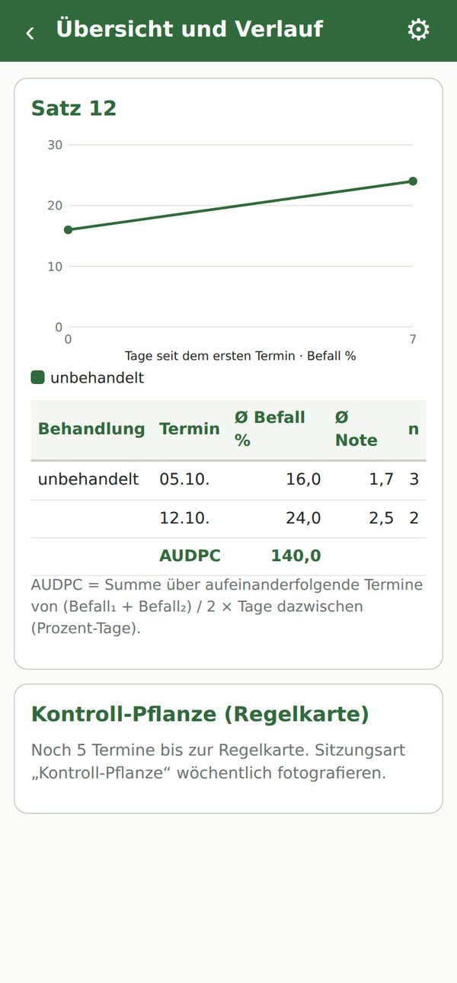
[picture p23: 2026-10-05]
docs/stand-und-fragen/bilder/app_uebersicht.jpg

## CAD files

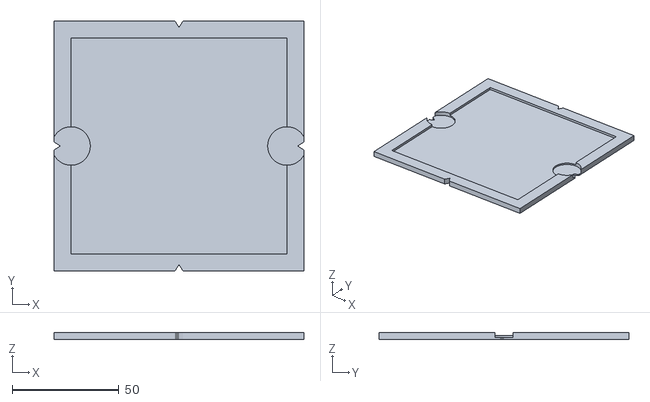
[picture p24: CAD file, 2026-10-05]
fotobox/stl/massstab_halter.stl
117.0 x 117.0 x 3.50

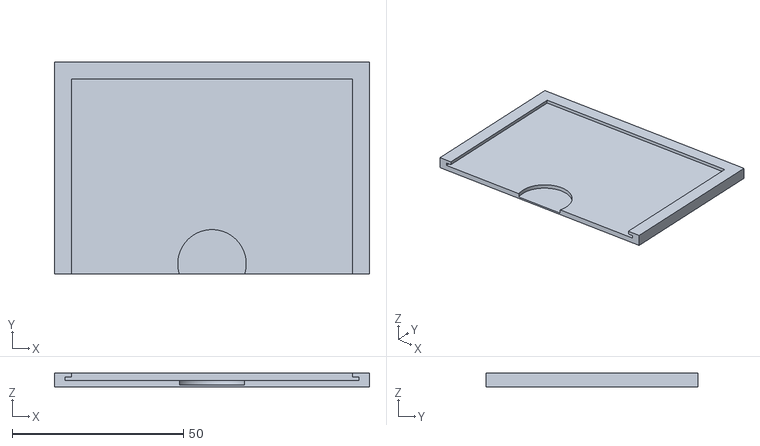
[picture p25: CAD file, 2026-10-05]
fotobox/stl/etikettenhalter.stl
92.0 x 62.0 x 4.20

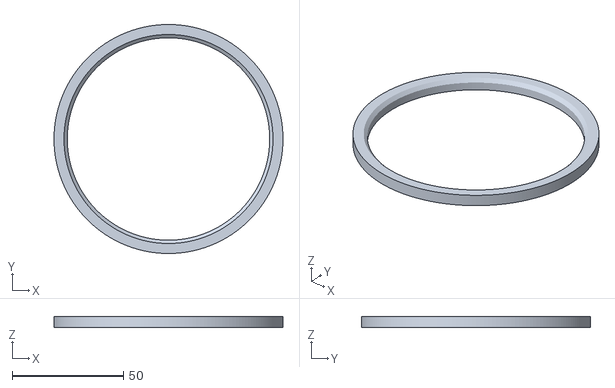
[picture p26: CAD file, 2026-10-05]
fotobox/stl/zentrierring.stl
103.0 x 103.0 x 5.00

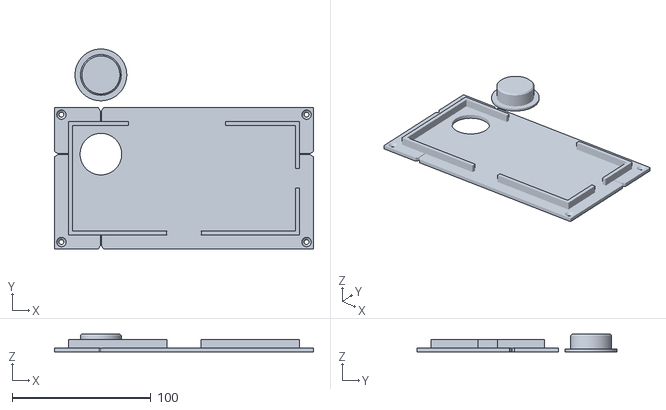
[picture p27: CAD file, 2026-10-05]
fotobox/stl/handyhalter.stl
187.0 x 144.4 x 13.0

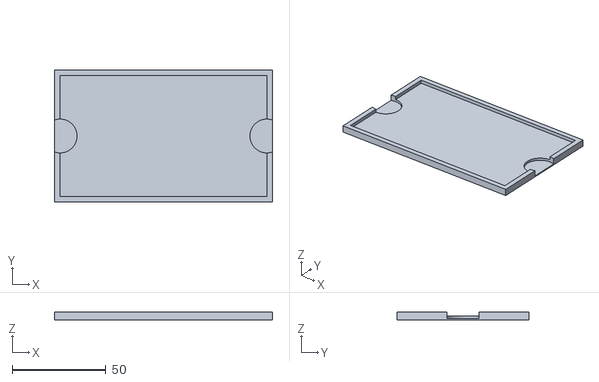
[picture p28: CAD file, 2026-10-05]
fotobox/stl/farbkarten_halter.stl
116.0 x 70.5 x 4.00

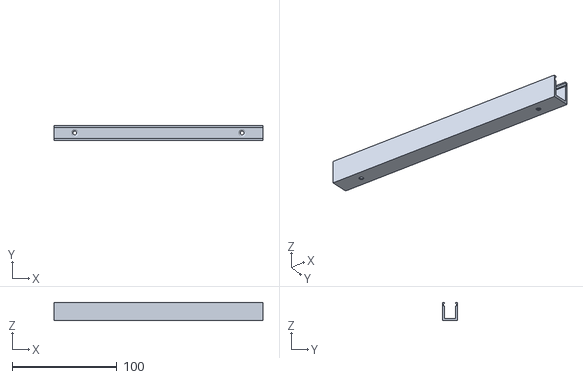
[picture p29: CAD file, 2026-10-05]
fotobox/stl/led_leiste.stl
200.0 x 14.6 x 17.6

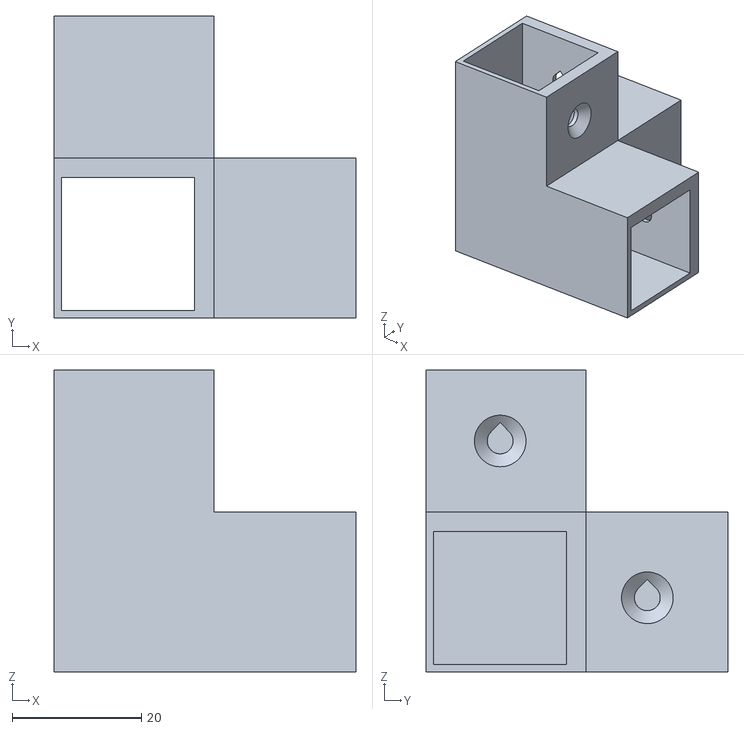
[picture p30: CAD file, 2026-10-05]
fotobox/stl/eckverbinder.stl
46.8 x 46.8 x 46.8

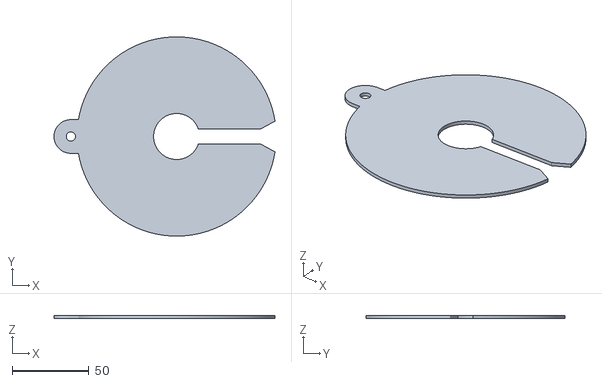
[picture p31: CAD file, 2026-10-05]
fotobox/stl/abdeckscheibe.stl
144.2 x 130.0 x 2.00

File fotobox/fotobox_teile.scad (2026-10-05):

// ============================================================================
//  Fotobox für die Mehltau-Bonitur – alle 3D-Druckteile in einer Datei
// ----------------------------------------------------------------------------
//  So benutzt du die Datei (OpenSCAD, kostenlos von openscad.org):
//   1. Datei öffnen. Rechts erscheint der "Customizer"
//      (falls nicht: Menü "Window"/"Fenster" -> Haken bei "Hide Customizer" weg).
//   2. Bei "teil" das gewünschte Teil auswählen.
//   3. Eigene Maße in den Gruppen unten eintragen (alle Maße in Millimetern).
//   4. F5 = schnelle Vorschau, F6 = Rendern, danach F7 bzw.
//      "File -> Export -> Export as STL" speichert die Druckdatei.
//  Alle Werte mit (PLATZHALTER) müssen gemessen und eingetragen werden.
//  Die Teile liegen schon in Druckrichtung (flache Seite unten, ohne Stützen).
//  Hinweise und Warnungen (z. B. "passt nicht aufs Druckbett") stehen
//  im Konsolen-Fenster unter "ECHO".
// ============================================================================

/* [Teil auswählen] */

// Welches Teil soll angezeigt bzw. exportiert werden?
teil = "eckverbinder"; // [eckverbinder, handyhalter, led_leiste, zentrierring, abdeckscheibe, farbkarten_halter, etikettenhalter, massstab_halter]

/* [Allgemein] */

// Passungs-Spiel je Seite in mm für Steckteile (Start 0.3; klemmt es: größer, wackelt es: kleiner)
spiel = 0.3;
// Druckbett: Breite in mm (nur für die Warnung)
druckbett_x = 220;
// Druckbett: Tiefe in mm (nur für die Warnung)
druckbett_y = 220;
// Druckbett: größte Druckhöhe in mm (nur für die Warnung)
druckbett_z = 250;

/* [Box] */

// Innenmaß der Box in mm (Breite = Tiefe, zwischen den Platten)
box_innen = 500;
// Innenhöhe der Box in mm (Boden bis Deckel) = Länge der senkrechten Leisten
box_hoehe = 700;
// Dicke der Platten (Wände, Deckel) in mm
platten_dicke = 5;
// Durchmesser des Kameralochs im Deckel in mm
deckel_loch_d = 30;

/* [Eckverbinder] */

// Leistenmaß in mm (Holzleiste mit dem Messschieber nachmessen; Alu-Profil 2020 = 20)
leiste = 20;
// Wandstärke der Hülsen innen (zur Box-Mitte hin) in mm
eck_wand_innen = 3;
// Wandstärke der Hülsen außen (unter den Platten) in mm, mindestens 0.8
eck_wand_aussen = 1.2;
// Steckhülsentiefe in mm: so weit stecken die waagerechten Leisten im Verbinder
eck_tiefe = 25;
// Schraublöcher in den Hülsen (4 Stück, zur Box-Innenseite)?
eck_schraubloch = true;
// Durchmesser der Schraublöcher in mm (Holzschraube 3.5 mm -> 4; Alu-Profil mit M5 -> 5.5)
eck_schraube_d = 4;
// Senkung für Senkkopfschrauben (bei Alu-Profil mit Linsenkopf: aus)?
eck_senkung = true;

/* [Handyhalter] */

// Handy: Länge (lange Seite) in mm, ohne Hülle (PLATZHALTER)
handy_laenge = 160;
// Handy: Breite (kurze Seite) in mm, ohne Hülle (PLATZHALTER)
handy_breite = 75;
// Handy: Dicke in mm, ohne Kamera-Buckel (PLATZHALTER)
handy_dicke = 9;
// Mitte der Hauptkamera-Linse: Abstand von der OBEREN Kante in mm, Handy hochkant von HINTEN gesehen (PLATZHALTER)
linse_von_oben = 20;
// Mitte der Hauptkamera-Linse: Abstand von der LINKEN Kante in mm, von HINTEN gesehen (PLATZHALTER)
linse_von_links = 20;
// Wo liegt die Oberkante des Handys im Halter, von oben aufs Display gesehen?
handy_oben = "links"; // [links, rechts]
// Spiel je Seite zwischen Handy und Halter in mm
handy_spiel = 0.5;
// Durchmesser des Linsenlochs im Halter in mm (wie das Loch im Deckel)
halter_linsenloch_d = 30;
// Kamera-Insel (Buckel): Abstand von der oberen Kante in mm, von hinten gesehen (0 = keine Aussparung)
insel_von_oben = 0;
// Kamera-Insel: Abstand von der linken Kante in mm, von hinten gesehen
insel_von_links = 0;
// Kamera-Insel: Breite in mm (quer, von hinten gesehen; 0 = keine Aussparung)
insel_breite = 0;
// Kamera-Insel: Höhe in mm (längs, von hinten gesehen; 0 = keine Aussparung)
insel_hoehe = 0;
// Bodendicke des Halters in mm
handy_boden = 3;
// Wandstärke um das Handy in mm
handy_wand = 3;
// Randhöhe über der Auflage in mm (etwas kleiner als die Handy-Dicke)
handy_randhoehe = 6;
// Breite des Schraubrands rundum in mm
handy_lasche = 10;
// Schraublöcher im Schraubrand in mm (4 Stück; M3-Schraube -> 3.4)
handy_schraube_d = 3.4;
// Breite der Aussparung für den Ladestecker in mm (0 = keine)
kabel_breite = 14;
// Ladebuchse: Versatz aus der Mitte der Unterkante in mm (von vorne gesehen, + = nach rechts)
kabel_versatz = 0;
// Seite der Tasten, Handy hochkant von VORNE (Display) gesehen
tasten_seite = "rechts"; // [rechts, links, keine]
// Tasten-Aussparung beginnt ... mm unter der oberen Kante (PLATZHALTER)
tasten_von = 40;
// Tasten-Aussparung endet ... mm unter der oberen Kante (PLATZHALTER)
tasten_bis = 110;
// Griffmulde in der vorderen Wand, damit man das Handy greifen kann?
griffmulde = true;
// Zentrierdorn mitdrucken (Hilfe zum Ausrichten über dem Deckel-Loch)?
zentrierdorn = true;

/* [LED-Leiste] */

// Breite des LED-Streifens in mm (nachmessen)
led_breite = 10;
// Länge eines Segments in mm (2 Segmente je Boxseite)
led_laenge = 200;
// Abstand LED-Streifen bis Diffusor in mm (größer = weicheres Licht)
led_abstand = 12;
// Dicke der Diffusorfolie bzw. Opal-Platte in mm
diffusor_dicke = 1;
// Wandstärke der Leiste in mm
led_wand = 2;
// Bodendicke der Leiste in mm
led_boden = 2;
// Schraublöcher im Boden der Leiste (2 Stück)?
led_schraubloch = true;
// Durchmesser der Schraublöcher in mm
led_schraube_d = 3.5;

/* [Zentrierring] */

// Maß B: Topf-Durchmesser unten in mm (größter Wert von 3 Töpfen) (PLATZHALTER)
topf_unten_B = 90;
// Zugabe zum Innendurchmesser in mm (Innenmaß = B + Zugabe)
ring_zugabe = 1;
// Ringhöhe in mm (niedrig halten)
ring_hoehe = 5;
// Ringbreite (Wandstärke) in mm
ring_breite = 6;
// Einführschräge oben innen in mm
ring_fase = 1.5;

/* [Abdeckscheibe] */

// Maß A: Topf-Durchmesser oben, Außenkante Rand, in mm (PLATZHALTER)
topf_oben_A = 120;
// Zugabe zum Durchmesser in mm (Scheibe = A + Zugabe)
scheibe_zugabe = 10;
// Maß G: Mittelloch für die Stängel in mm (PLATZHALTER)
stiel_loch_G = 30;
// Dicke der Scheibe in mm
scheibe_dicke = 2;
// Breite des Schlitzes vom Rand bis zur Mitte in mm
schlitz_breite = 10;
// Griffnase mit Aufhängeloch?
griffnase = true;
// Länge der Griffnase über den Rand hinaus in mm
griffnase_laenge = 15;

/* [Farbkarten- und Etikettenhalter] */

// Sockelhöhe in mm (0 = flach auf dem Boden; z. B. 100, wenn große Pflanzen die Karte verdecken)
sockel_hoehe = 0;
// Befestigung am Boxboden (schrauben: versenkte Löcher unter der Karte)
befestigung = "kleben"; // [kleben, schrauben]
// Durchmesser der Befestigungsschrauben in mm
befestigung_schraube_d = 3.5;
// Bodendicke unter der Karte in mm
karte_boden = 2;
// Breite des Rahmens um die Karte in mm (schmal)
karte_rand = 3;
// Spiel je Seite um die Karte in mm
karten_spiel = 0.5;
// Dicke der Halte-Lippen über dem Kartenrand in mm
lippe_dicke = 1.2;
// Farbkarte: Breite (kurze Seite) in mm
farbkarte_breite = 63.5;
// Farbkarte: Länge (lange Seite) in mm
farbkarte_laenge = 109;
// Farbkarte: Dicke in mm (PLATZHALTER, nachmessen)
farbkarte_dicke = 2;
// Farbkarte: Lippe über dem Kartenrand in mm (0 = keine, dann verdeckt nichts die Farbfelder)
farbkarte_lippe = 0;
// Topf-Karte (Etikett): Länge in mm
etikett_laenge = 85;
// Topf-Karte: Breite in mm
etikett_breite = 55;
// Topf-Karte: Dicke in mm
etikett_dicke = 0.5;
// Topf-Karte: Lippe über dem Kartenrand in mm (hält Papier flach; Rand der Karte frei lassen)
etikett_lippe = 2;

/* [Maßstab-Halter] */

// Kantenlänge der quadratischen Maßstab-Karte in mm
massstab_karte = 100;
// Dicke der Maßstab-Karte (Papier auf Karton) in mm
massstab_dicke = 1.5;
// Breite des Rands um die Karte in mm
massstab_rand = 8;
// Bodendicke unter der Karte in mm
massstab_boden = 2;

/* [Hidden] */

// ---------------------------------------------------------------------------
// Ab hier: abgeleitete Werte und Zeichenbefehle - normalerweise nichts ändern.
// ---------------------------------------------------------------------------
$fa = 2;      // Kreise: höchstens 2 Grad je Kante
$fs = 0.4;    // Kreise: Kantenlänge höchstens 0.4 mm
e = 0.01;     // kleine Zugabe, damit Schnitte sauber durchgehen

// Eckverbinder
eck_wa = max(eck_wand_aussen, 0.8);          // Außenwand (mindestens 0.8 mm)
eck_h  = leiste + 2 * spiel;                  // Lochweite der Hülse
eck_s  = eck_wa + eck_h + eck_wand_innen;     // Außenmaß einer Hülse (Querschnitt)
eck_E  = eck_wa + eck_h + eck_tiefe;          // Länge jeder Hülse ab der Ecke
// Zuschnitt: senkrechte Leisten = Innenhöhe; waagerechte stoßen an die senkrechten
leiste_senkrecht  = box_hoehe;
leiste_waagerecht = box_innen - 2 * (eck_wa + spiel + leiste);

// ============================================================================
//  Hilfsfunktionen
// ============================================================================

// auf 1 Nachkommastelle runden (für die Meldungen)
function r1(x) = round(x * 10) / 10;
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

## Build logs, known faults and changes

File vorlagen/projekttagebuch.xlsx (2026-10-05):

datum | etappe | erledigt | entscheidung | offene_fragen | naechster_schritt
05.10.2026 | 0 | Claude hat Analyse-Kern, Werkstatt, Handy-App, Druckseite, Vorlagen und Druckteile vorab gebaut (PDF „Stand und Fragen“) |  | Fragen F1–F15 aus dem PDF | Werkstatt-Demo ansehen, GitHub einrichten, Fragen beantworten, messen

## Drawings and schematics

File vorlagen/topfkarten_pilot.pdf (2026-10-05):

P001 P002

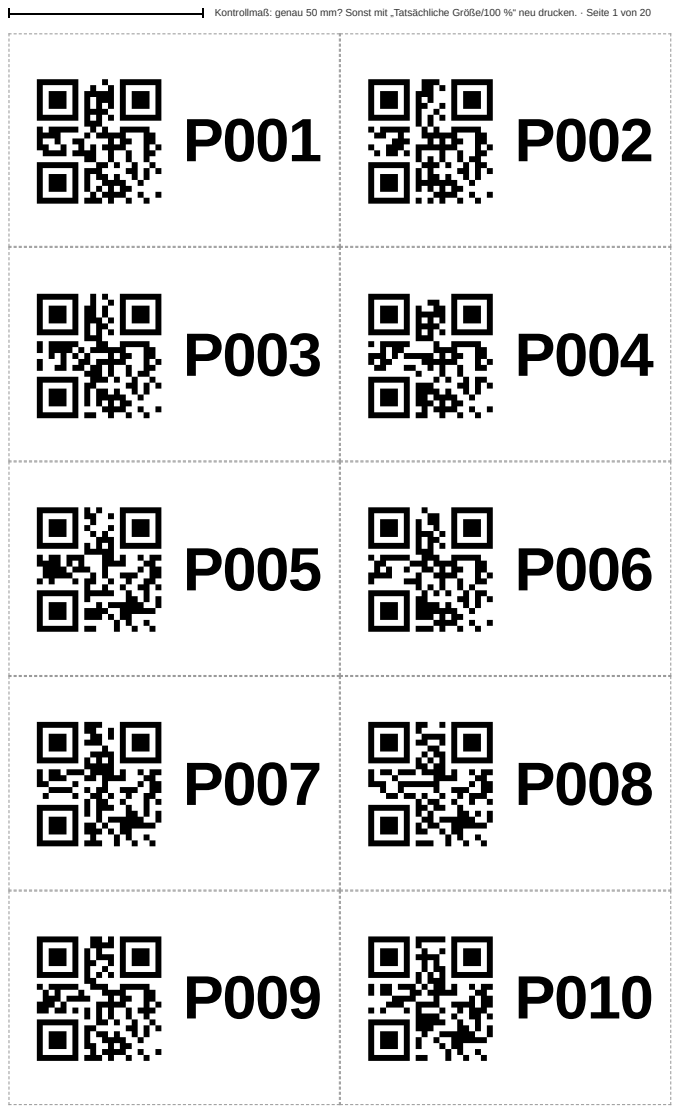
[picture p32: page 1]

Kontrollmaß: genau 50 mm? Sonst mit „Tatsächliche Größe/100 %“ neu drucken. · Seite 1 von 20

P011 P012

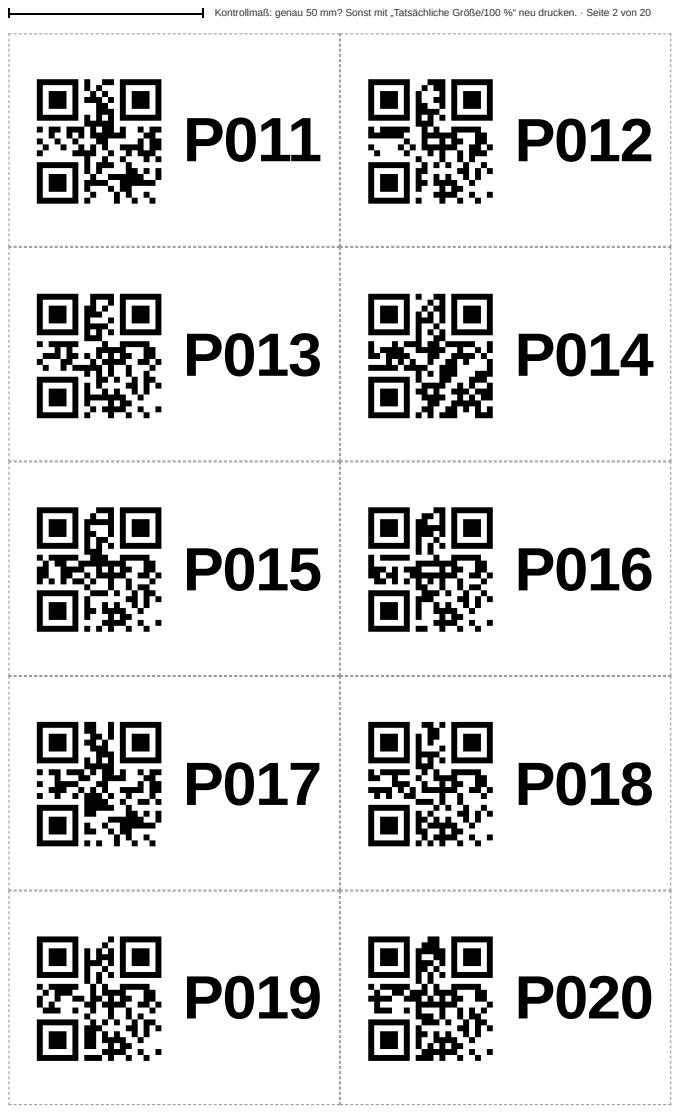
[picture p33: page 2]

Kontrollmaß: genau 50 mm? Sonst mit „Tatsächliche Größe/100 %“ neu drucken. · Seite 2 von 20

P021 P022

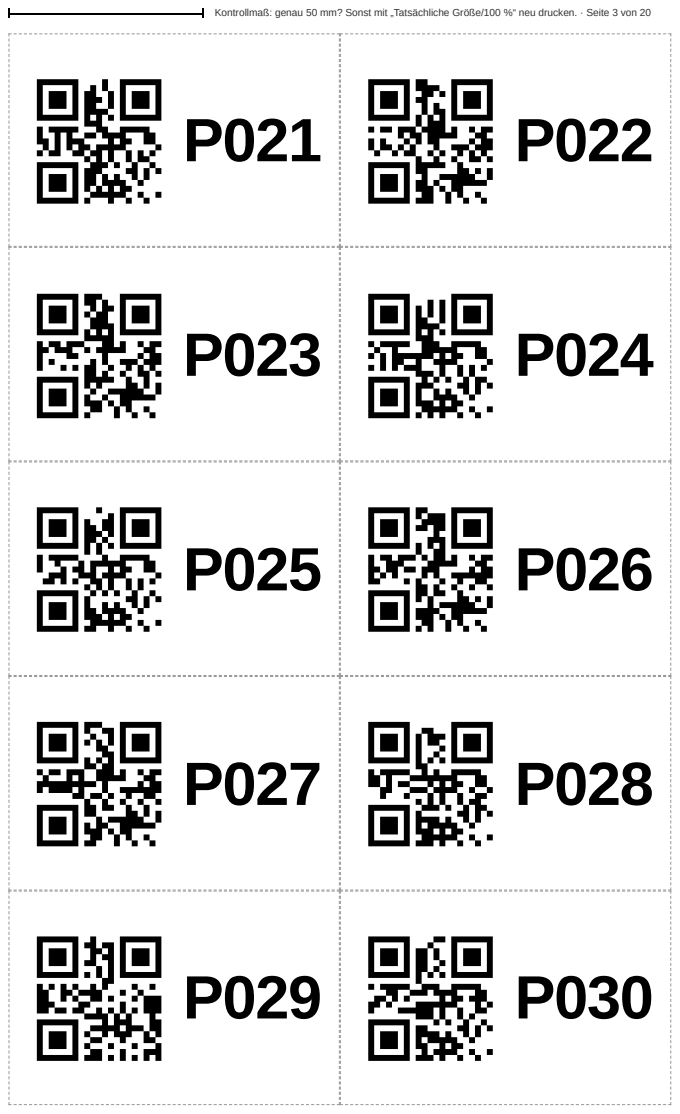
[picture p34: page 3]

Kontrollmaß: genau 50 mm? Sonst mit „Tatsächliche Größe/100 %“ neu drucken. · Seite 3 von 20

P031 P032

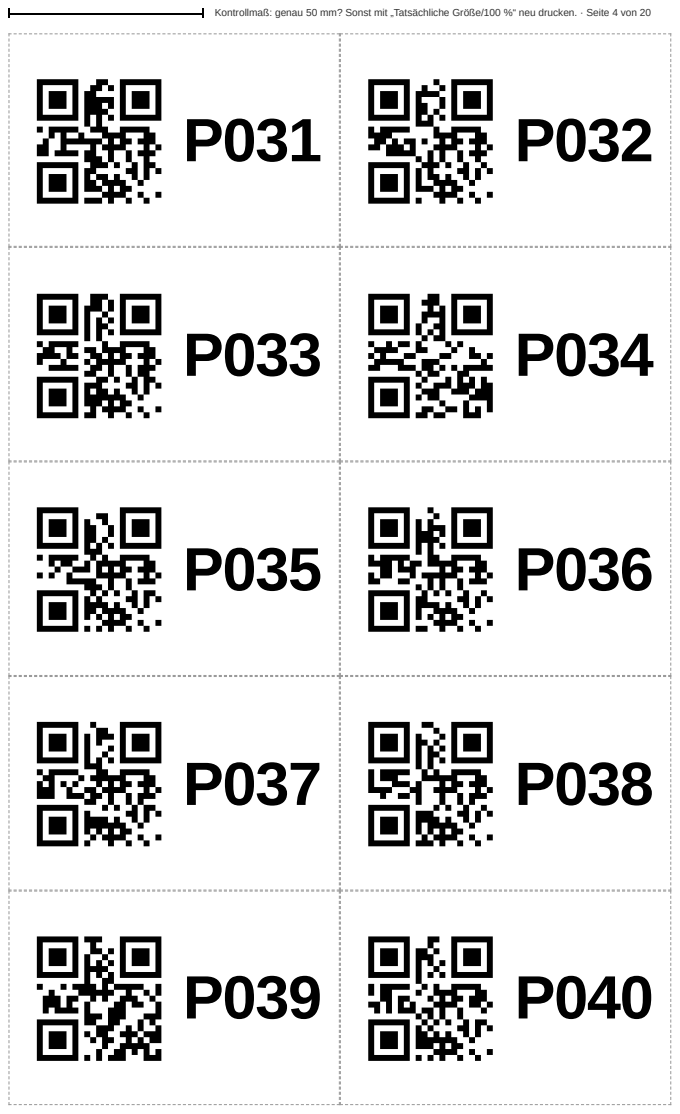
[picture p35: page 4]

Kontrollmaß: genau 50 mm? Sonst mit „Tatsächliche Größe/100 %“ neu drucken. · Seite 4 von 20

P041 P042

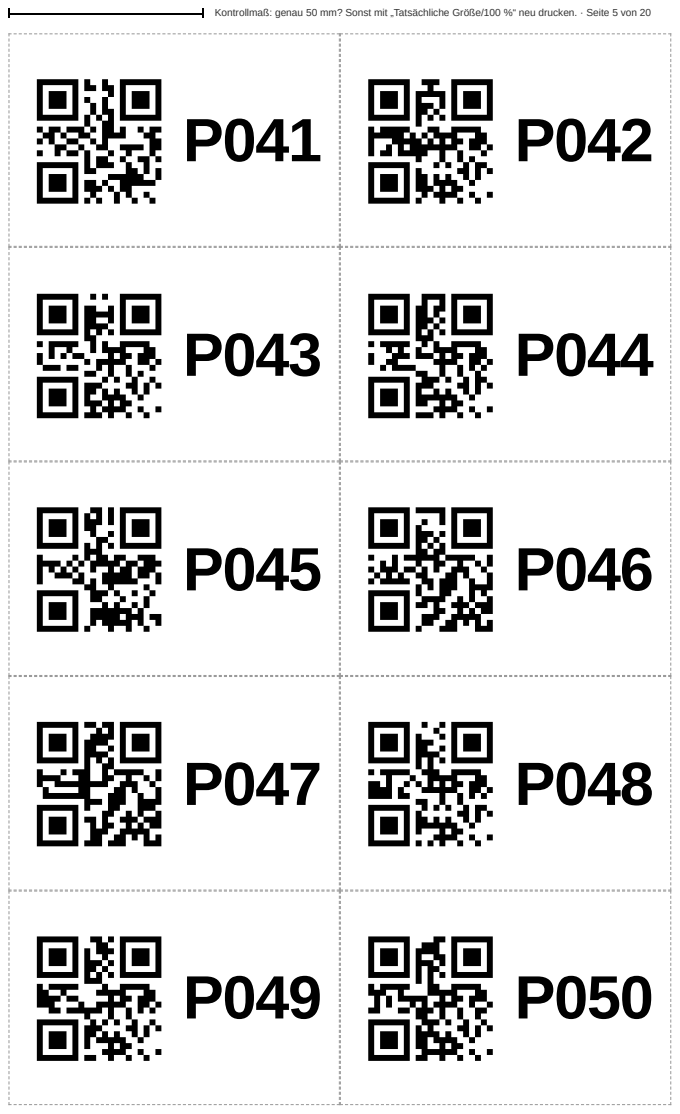
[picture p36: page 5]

Kontrollmaß: genau 50 mm? Sonst mit „Tatsächliche Größe/100 %“ neu drucken. · Seite 5 von 20

P051 P052

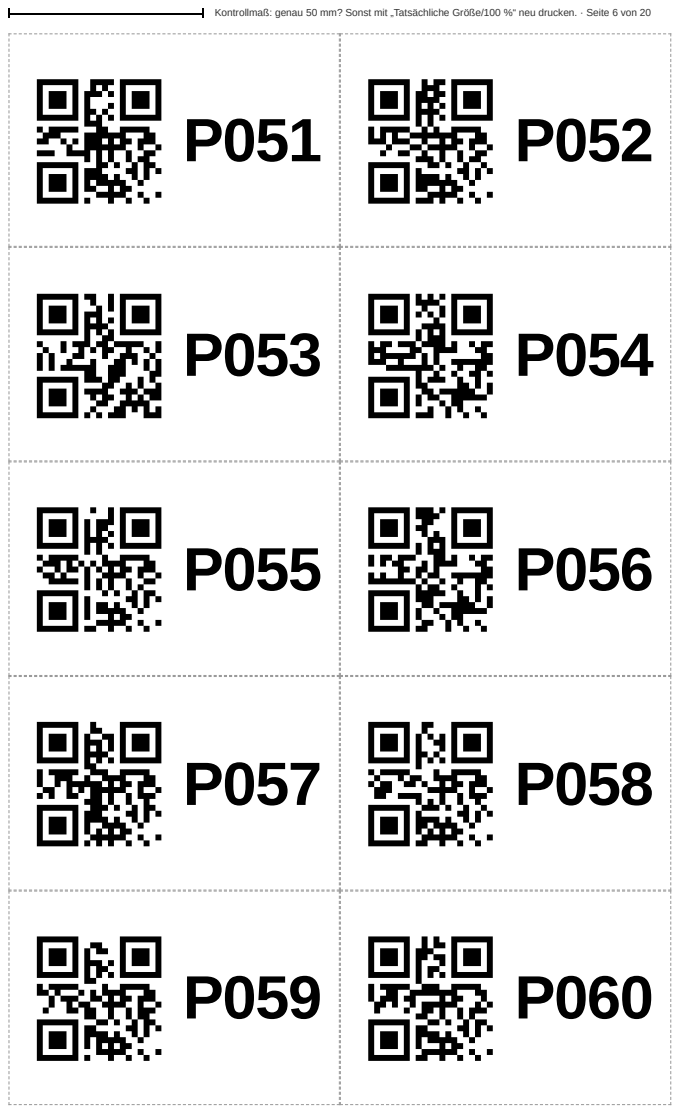
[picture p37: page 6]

Kontrollmaß: genau 50 mm? Sonst mit „Tatsächliche Größe/100 %“ neu drucken. · Seite 6 von 20

P061 P062

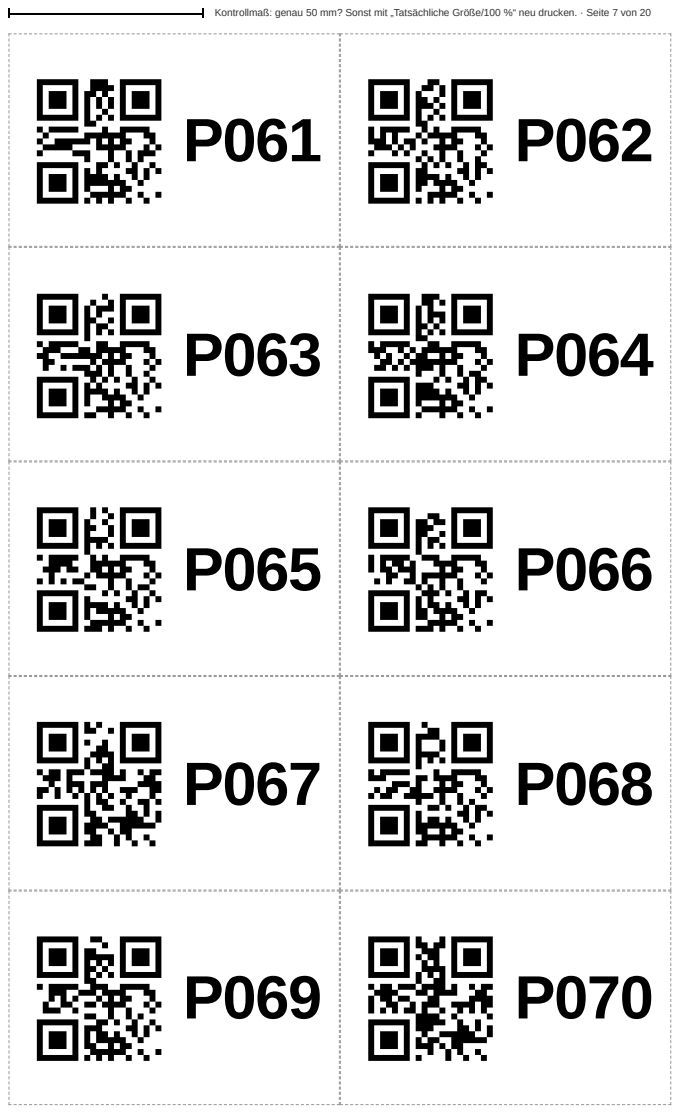
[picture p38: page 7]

Kontrollmaß: genau 50 mm? Sonst mit „Tatsächliche Größe/100 %“ neu drucken. · Seite 7 von 20

Kontrollmaß: genau 50 mm? Sonst mit „Tatsächliche Größe/100 %“ neu drucken. · Seite 8 von 20
P071 | P072
P073 | P074
P075 | P076
P077 | P078
P079 | P080

Kontrollmaß: genau 50 mm? Sonst mit „Tatsächliche Größe/100 %“ neu drucken. · Seite 9 von 20
P081 | P082
P083 | P084
P085 | P086
P087 | P088
P089 | P090

P091 P092

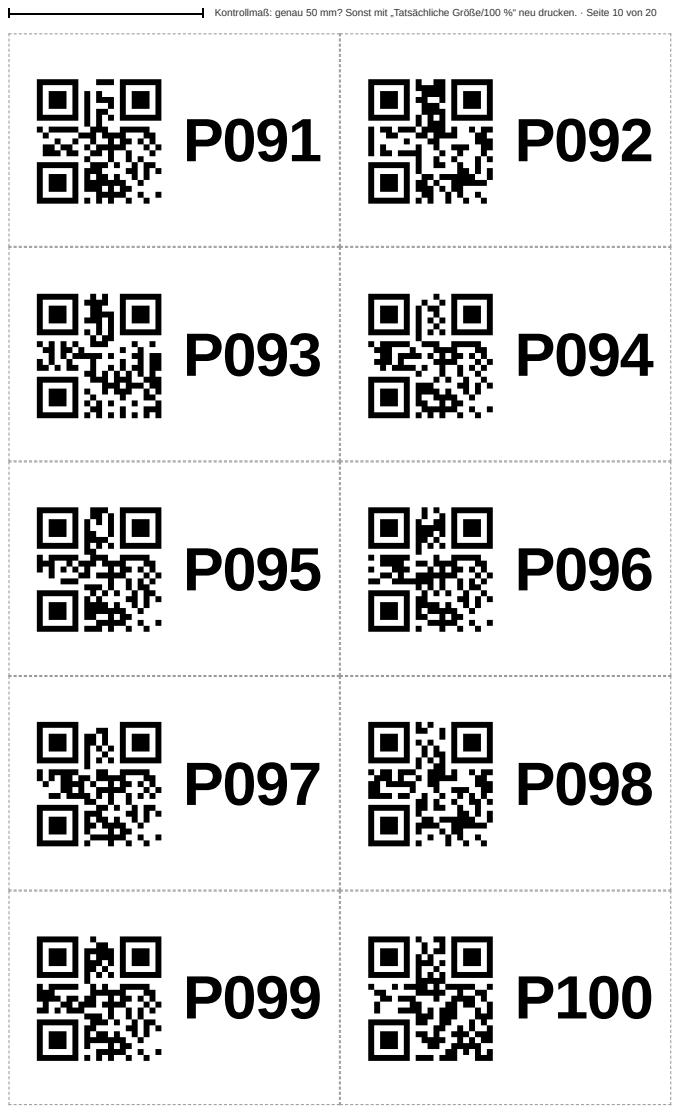
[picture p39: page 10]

Kontrollmaß: genau 50 mm? Sonst mit „Tatsächliche Größe/100 %“ neu drucken. · Seite 10 von 20

P101 P102

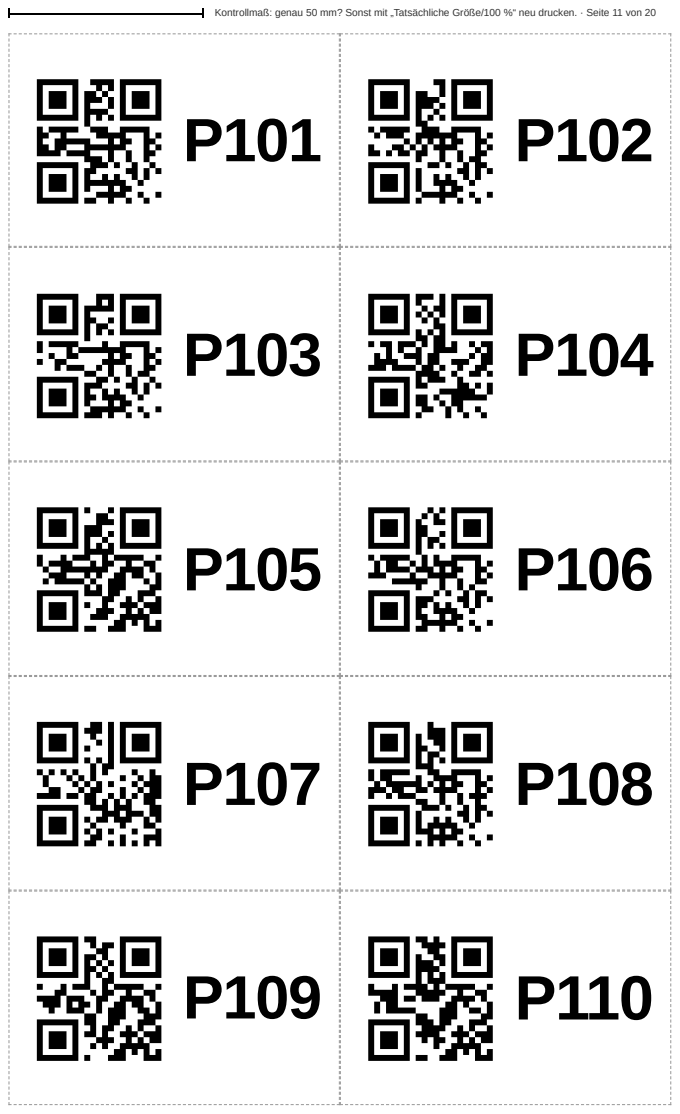
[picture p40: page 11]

Kontrollmaß: genau 50 mm? Sonst mit „Tatsächliche Größe/100 %“ neu drucken. · Seite 11 von 20

P111 P112

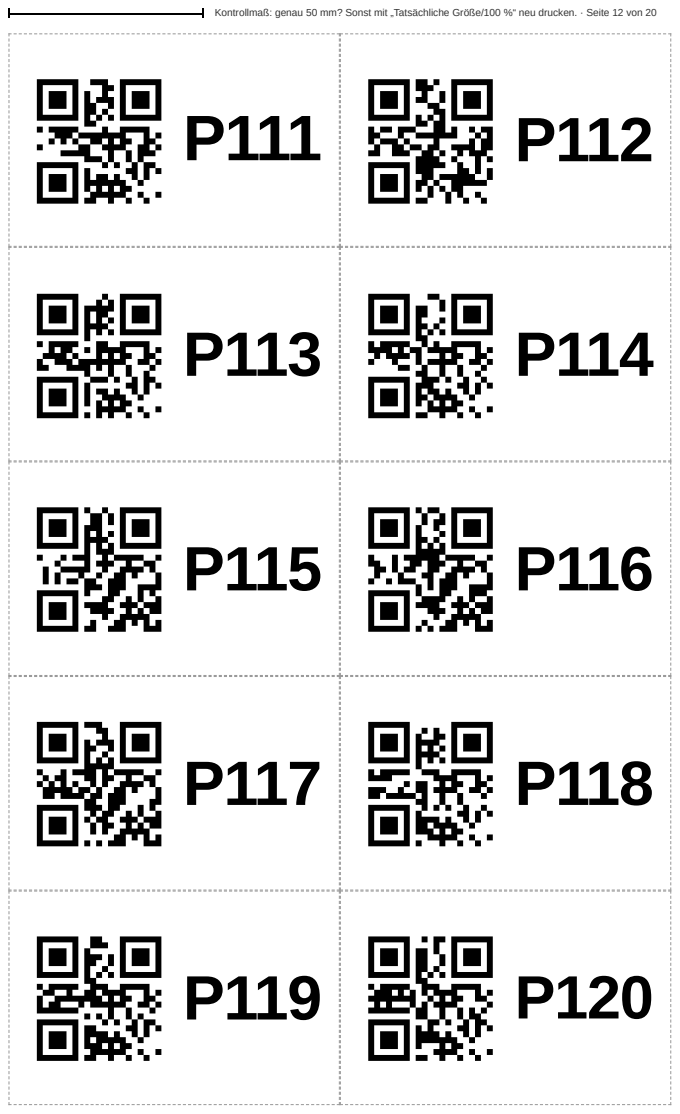
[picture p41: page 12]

Kontrollmaß: genau 50 mm? Sonst mit „Tatsächliche Größe/100 %“ neu drucken. · Seite 12 von 20

Kontrollmaß: genau 50 mm? Sonst mit „Tatsächliche Größe/100 %“ neu drucken. · Seite 13 von 20
P121 | P122
P123 | P124
P125 | P126
P127 | P128
P129 | P130

P131 P132

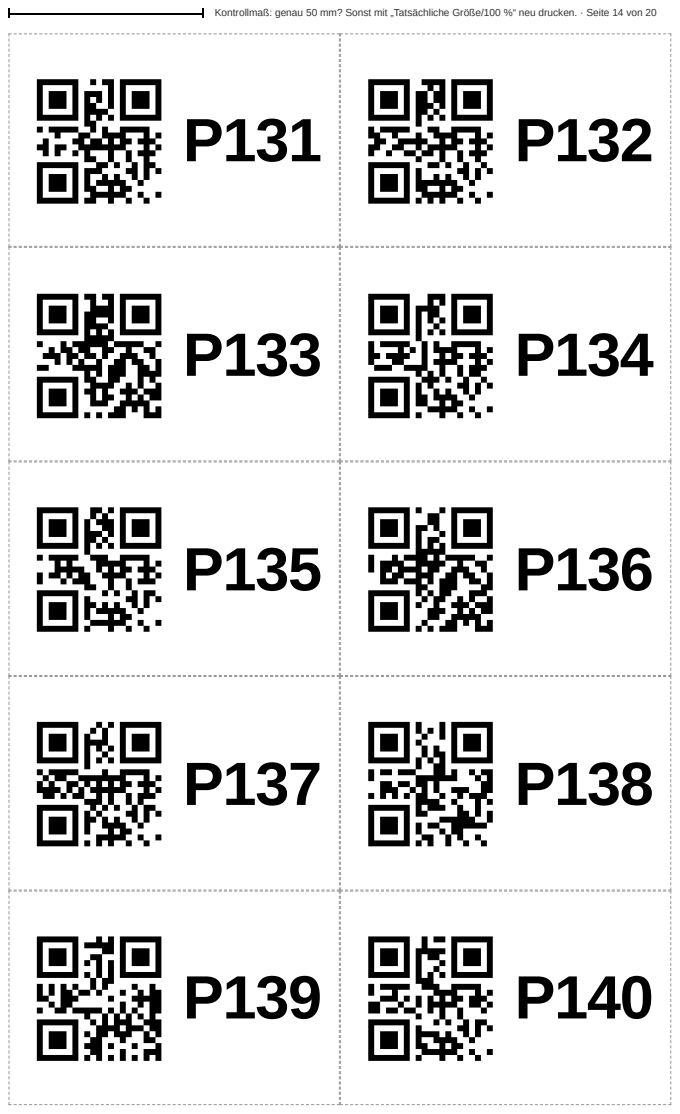
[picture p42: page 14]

Kontrollmaß: genau 50 mm? Sonst mit „Tatsächliche Größe/100 %“ neu drucken. · Seite 14 von 20

P141 P142

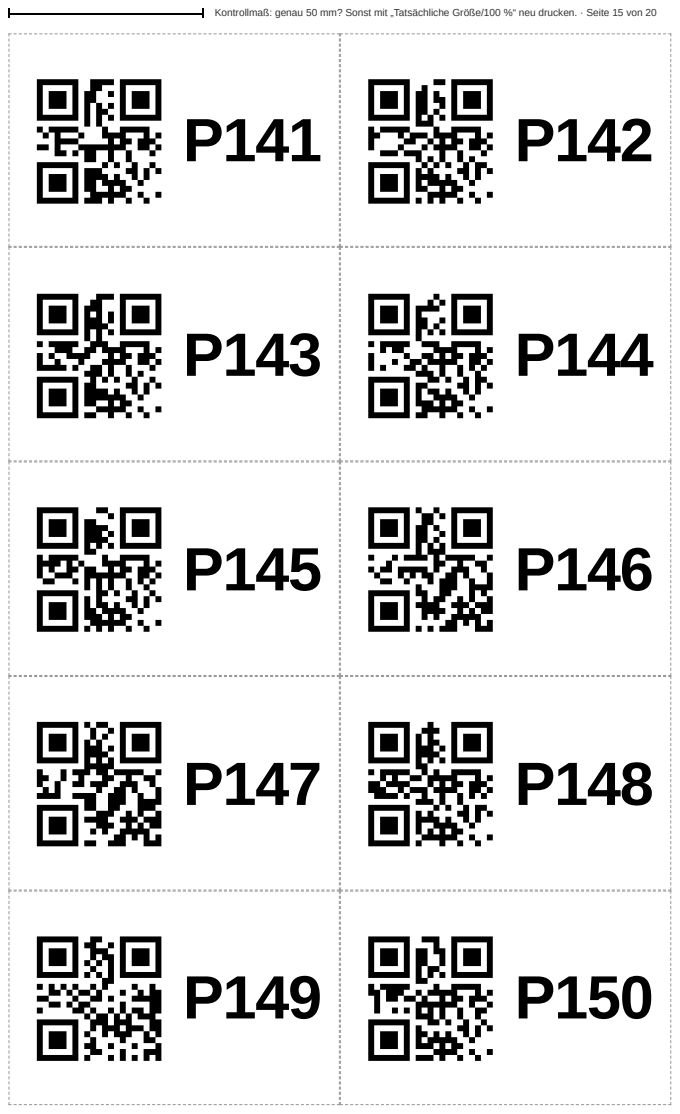
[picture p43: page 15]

Kontrollmaß: genau 50 mm? Sonst mit „Tatsächliche Größe/100 %“ neu drucken. · Seite 15 von 20

P151 P152


Kontrollmaß: genau 50 mm? Sonst mit „Tatsächliche Größe/100 %“ neu drucken. · Seite 16 von 20

P161 P162


Kontrollmaß: genau 50 mm? Sonst mit „Tatsächliche Größe/100 %“ neu drucken. · Seite 17 von 20

Kontrollmaß: genau 50 mm? Sonst mit „Tatsächliche Größe/100 %“ neu drucken. · Seite 18 von 20
P171 | P172
P173 | P174
P175 | P176
P177 | P178
P179 | P180

P181 P182


Kontrollmaß: genau 50 mm? Sonst mit „Tatsächliche Größe/100 %“ neu drucken. · Seite 19 von 20

P191 P192


Kontrollmaß: genau 50 mm? Sonst mit „Tatsächliche Größe/100 %“ neu drucken. · Seite 20 von 20

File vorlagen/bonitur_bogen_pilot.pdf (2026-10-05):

## 6.8 Kopiervorlage: Bonitur-Bogen

Leitfaden Mehltau-Bonitur; Seite 37; Nekrosen; Topf-Nr.; Sorte; Note; Befall %; Sporen; unten; Bemerkung; ja · nein

Für jede Person und jede Sitzung ein eigener Bogen. Die Spalte „Sporen unten“ füllt nur die eingeteilte Person

aus, nach dem Foto.

Bonitur-Bogen – Pilot (Etappe 3)

Datum: ______________ Person (Kürzel): ________ Satz: __________ Blatt ____ von ____

Skala: 0 keine Symptome · 1 bis 10 % · 2 über 10 bis 25 % · 3 über 25 bis 50 % · 4 über 50 % oder starke

Regeln: allein bonitieren, nicht absprechen · ganze Noten · Befall % = gelbe und braune Blattfläche an

der ganzen Pflanze · vor dem Foto keine Blätter anfassen

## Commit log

2026-09-30 Konzept und Machbarkeitsanalyse für Mehltau-Bonitur-App
    Beschreibt Messprinzip (Farbanalyse), Fotobox, App-Architektur,
    Kalibrierung, Risiken und Fahrplan.
    Claude-Session: https://claude.ai/code/session_018FVCHoG9m98xszLg23Bk1e
2026-09-30 Leitfaden als PDF, technische Spezifikation und Quelldateien
    docs/Leitfaden_Mehltau-Bonitur.pdf: 95 Seiten, führt Schritt für Schritt
    durch alle Etappen (Vorbereitung, Fotobox, Box-Handy, Pilot, Auswertung
    und Go/No-Go, App-Bau mit Claude in Bausteinen B1–B9 mit Kopier-Prompts,
    Kalibrierung, Betrieb), mit Checklisten, Kopiervorlagen, Glossar, Quellen.
    docs/SPEZIFIKATION.md: verbindliche Zahlen und Vorgaben, auf die die
    Prompts im Leitfaden verweisen.
    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
2026-10-05 Analyse-Kern (B1) mit Tests und synthetischen Testbildern
    kern/: Farbumrechnung, Farbkarte (24 Felder, Sollwerte ab 11/2014),
    Farbkorrektur (3x3 in linearem RGB), Verkleinern, Auswertekreis, HSV,
    Kandidaten mit Fleckenentfernung, Klassen grün/gelb/braun, Kennzahlen,
    Noten, Qualitätschecks, Kontrollbild, Histogramm für sofortige
    Regler-Neuberechnung, Statistik (Kappa, Spearman, AUDPC), QR, EXIF.
    werkzeuge/synthetik.js erzeugt Box-Fotos mit bekannter Wahrheit.
    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
2026-10-05 Analyse-Werkstatt (B2) mit Demo-Modus und Einzeldatei-Fassung
    werkstatt/: Fotos und Bonitur-Excel laden, Einrichten (Farbkarte mit
    Lupe und automatischer Eckenreihenfolge, Topfkreis, Etikettbereich,
    Maßstab-Karte), Stapelauswertung mit mehreren Workern, Zuordnung über
    foto_datei und QR-Code, Kontrollbilder mit Filtern und Detailansicht,
    Regler mit sofortiger Wirkung (Histogramme), Streudiagramm, Kappa,
    Spearman, Wiederholbarkeit, Lichttest, unsichtbarer Befall,
    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
2026-10-05 Handy-App (B3–B9), Druckseite für Topf-Karten (B7) und Startseite
    - app/: Offline-Web-App (PWA) mit Sitzungen, Foto-Import und Direktaufnahme,
    Analyse im Hintergrund, Kontrollbild, QR-Topf-ID, Sicht-Bonitur mit
    Referenzfotos, Export als Excel und ZIP, Löschen erst nach Sicherung,
    Verlauf mit AUDPC, Regelkarte der Kontroll-Pflanze, Einstellungen mit PIN,
    Einrichten am Handy und Kamera-Test.
    - etiketten/: Topf-Karten 85 × 55 mm mit großer Nummer und QR-Code
    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
2026-10-05 Vorlagen für den Pilot: Topf-Karten, Maßstab-Karte, Excel, Bonitur-Bogen
    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
    [pilot_bonitur_vorlage.xlsx]
2026-10-05 App: Stammdaten-Excel, Maßstab, Testversion, Export-Rücklesetest; GitHub-Abläufe
    - Stammdaten als Excel speichern und ergänzen; Maßstab-Karte am Handy einstellen.
    - Übersicht mit einer Zeile je Termin (Ø Befall, Ø Note, n) und AUDPC.
    - Blatt „Sitzung“ im Export mit Versionen und verwendeten Einstellungen;
    ZIP heißt wie die Sitzung (2027-02-10_Satz12.zip).
    - Bild antippen zum Vergrößern; Dateigröße des Originalfotos.
    - Datenmodell: Schema-Migrationen und Ergänzen älterer Messungen (mit Test).
    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
2026-10-05 Projektregeln, Fortschritt, Spezifikation; Tests in GitHub Actions mit Node 22
    - CLAUDE.md: Zusammenarbeit, Datenschutz, Technik, Ordner, Versionen, Tests, Fallstricke.
    - docs/FORTSCHRITT.md: Stand B1–B9 und Etappen, offene Punkte je Baustein.
    - docs/SPEZIFIKATION.md: festgelegte Werte (ΔE-Grenzen 6/12, Fleckenfilter 30 Pixel,
    Qualitätschecks, Einstellungsdatei, Kennungen, Exportnamen, Testversion).
    - Hinweis „sichtbare Symptome von oben – keine Mehltau-Diagnose“ in App, Export, Werkstatt.
    - GitHub Actions: Node 22 (Node 20 kennt keine Muster in node --test).
    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
2026-10-05 Vorlage Projekttagebuch; Hinweise für Entwickler
    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
    [pilot_bonitur_vorlage.xlsx, projekttagebuch.xlsx]
2026-10-05 Entwurf „Stand und Fragen“ (PDF + Quelle) und Zwischenstand der 3D-Druckteile
    - docs/stand-und-fragen/: Quelle und Bauskript des PDFs mit Stand, nächsten Schritten,
    Fragen F1–F15, Messbögen und Antwort-Prompt; docs/Stand_und_Fragen.pdf (Entwurf).
    - druckteile/: OpenSCAD-Datei mit allen Teilen, STL-Dateien, Vorschaubilder, Anleitung
    (Zwischenstand, wird noch geprüft).
    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
    [abdeckscheibe.stl, eckverbinder.stl, etikettenhalter.stl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]
2026-10-05 3D-Druckteile im Ordner fotobox/ (wie im Leitfaden), PDF „Stand und Fragen“ fertig
    - fotobox/: eine OpenSCAD-Datei mit allen 8 Teilen (Eckverbinder, Handyhalter, LED-Leiste,
    Zentrierring, Abdeckscheibe, Farbkarten-, Etiketten- und Maßstab-Halter), STL-Dateien mit
    Standardwerten, Vorschaubilder, Anleitung mit Zuschnittliste und Platzhalter-Liste.
    - Topf-Karten: mindestens 4 mm Rand, weil der Etikettenhalter 2 mm breite Lippen hat
    (QR-Code mit simulierten Lippen bei Box-Auflösung gelesen); Vorlagen neu erzeugt.
    - docs/Stand_und_Fragen.pdf: Stand, nächste Schritte, Fragen F1–F15, Messbögen,
    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
    [abdeckscheibe.stl, eckverbinder.stl, etikettenhalter.stl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]
2026-10-05 Safari: Farbkarte und Auswertung in der Werkstatt als Datei, Fotos speichern in der App
    Fehlerbild (gemeldet): In Safari brach das Einrichten der Farbkarte in der Werkstatt
    (als Datei per Doppelklick geöffnet) mit „An error occured reading the Blob argument to
    createImageBitmap“ ab.
    - kern/arbeiter.js: Fotos werden im Hauptprogramm dekodiert und als ImageBitmap (+ Dateianfang
    für EXIF) an den Worker gegeben – Safari kann unter file:// im Worker keine Bilder dekodieren.
    Dekodiert wird erst, wenn ein Worker frei ist.
    - app/db.js: Bilder als ArrayBuffer + Typ speichern; Safari lehnt Blobs in IndexedDB ab
    („Error preparing Blob/File data to be stored“), die App blieb dort nach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
